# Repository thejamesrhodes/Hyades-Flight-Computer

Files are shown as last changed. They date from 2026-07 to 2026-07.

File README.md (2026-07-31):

<p align="center">
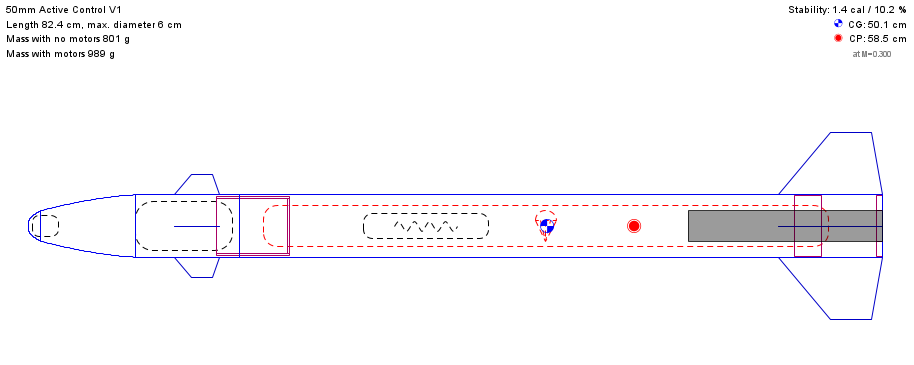
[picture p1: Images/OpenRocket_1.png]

</p>

---

# Hyades Flight Computer

Custom STM32H743 flight computer and GNC software for an actively roll-controlled high-power rocket.






*This is an engineering project, not a product. The safety case, regulatory compliance, and airworthiness of any vehicle built from this material are the builder's sole responsibility.*

The project is designed to:
- Provide a modular active roll-stabilisation system suitable for a wide range of high-power rockets.
- Improve flight data quality by reducing excessive vehicle roll.
- Improve parachute deployment reliability by limiting roll-induced line twist.
- Provide a reusable avionics platform for future guidance, navigation and control research.
- Maintain compliance with applicable rocketry regulations through both hardware and software design decisions.
- Release all hardware, firmware and simulation tools as open source.

This repository contains the hardware design, embedded software, simulation models, and analysis tools used during development.

---

## Specification

## Specification

| Parameter | Specification |
|---|---|
| Purpose | Active roll stabilisation for mid- and high-power rockets |
| Flight Computer | STM32H743 ARM Cortex-M7 |
| Control Surfaces | Four independently actuated canards |
| Control System | Configurable closed-loop roll controller with dynamic-pressure gain scheduling |
| Interfaces | I²C, UART and 6× PWM outputs |
| Data | On-board logging with optional telemetry |
| Simulation | MATLAB, Simulink, 6DOF modelling and Monte Carlo analysis |
| Architecture | Modular flight computer, sensor board and power distribution board |
| Design Goals | Low mass, modular, reliable and adaptable |
| License | Apache 2.0 |

---

## Project Progress

| Feature | Status |
|---|:---:|
| Flight Computer Design | ✅ Complete |
| Flight Computer Testing | 🚧 In Progress |
| Flight Software | 🚧 In Progress |
| Flight Hardware Design | 🚧 In Progress |
| Flight Hardware Testing | 🚧 In Progress |
| Simulink Roll Model | ✅ Complete |
| Simulink 6DOF Model | ✅ Complete |
| MATLAB Monte Carlo Analysis | ✅ Complete |
| MATLAB Gain Optimisation | ✅ Complete |
| System Integration | ⏳ Not Started |
| HITL Testing | ⏳ Not Started |
| Flight Testing | ⏳ Not Started |

---

## Repository Structure

```text
Hyades-Flight-Computer
│
├── Firmware/
├── Hardware/
│   ├── PDB/
│   └── MCU Board/
├── Simulation/
│   ├── Buck Regulator/
│   ├── HSE Clock/
│   └── Roll Tuning/
├── Images/
└── Documentation/
```

---

## Flight Computer Design

The main PCB, containing all the computation and data gathering.

<p align="center">
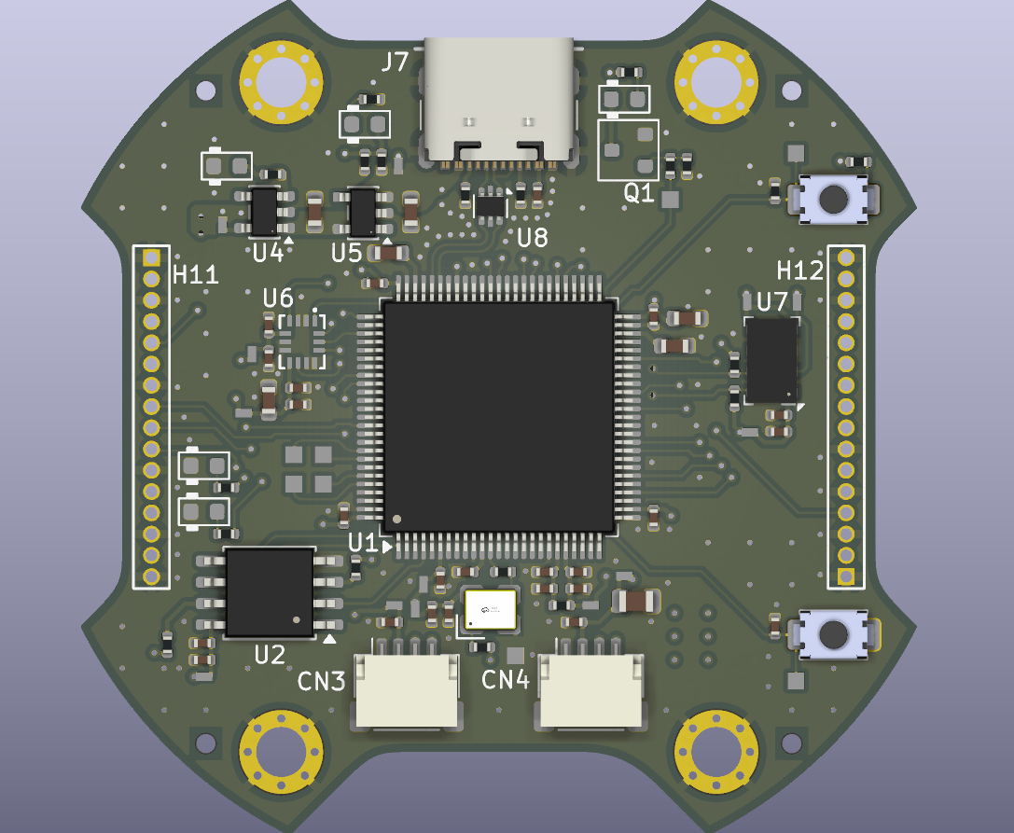
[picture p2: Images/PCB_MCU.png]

</p>

The PDB board, provides power and distributes PWM signals to the servos, as well as providing a clean 3V3 to the sensor board.

<p align="center">
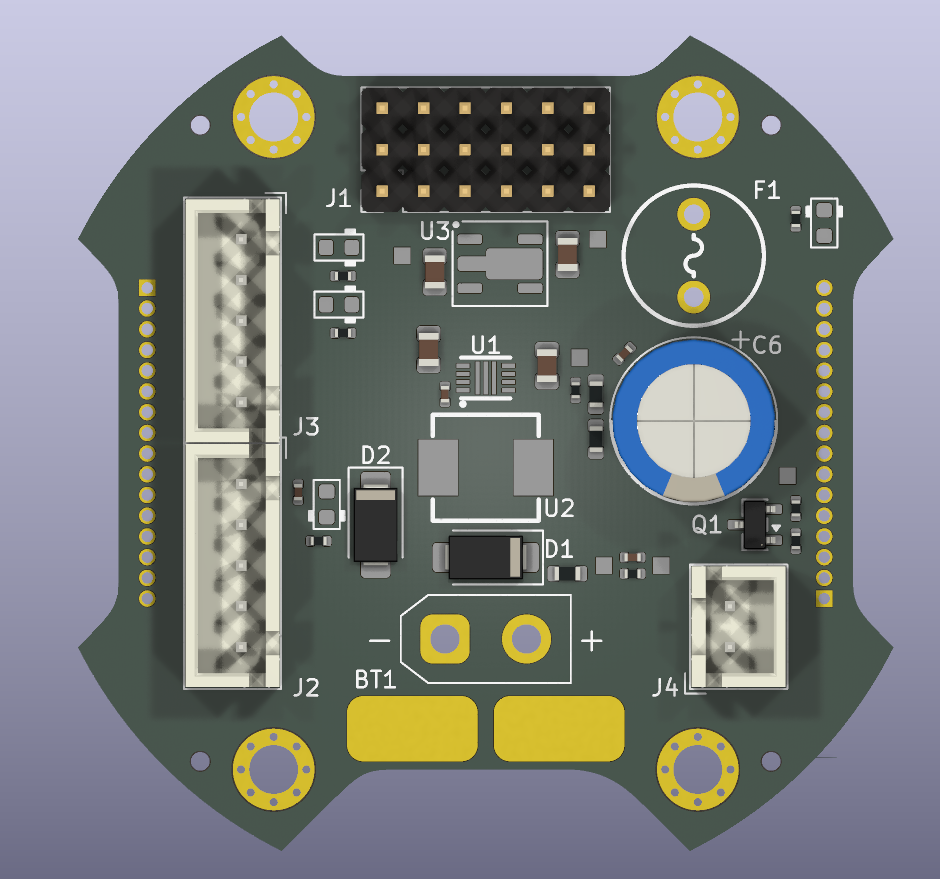
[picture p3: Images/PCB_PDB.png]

</p>

---

## Flight Computer Testing

0 Ohm Series Termination vs 47 Ohm Series Termination for the 24Mhz HSE Oscillator, unnecessary? Yes, but a good opportunity to learn SPICE Simulations, plus it looks cool.
Below the schematic that the simulations where derived from.

<p align="center">
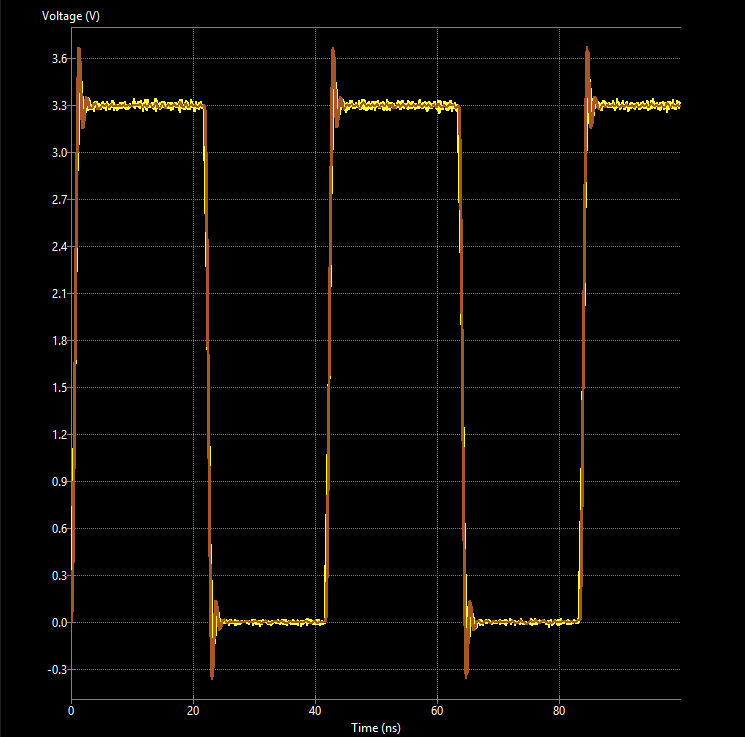
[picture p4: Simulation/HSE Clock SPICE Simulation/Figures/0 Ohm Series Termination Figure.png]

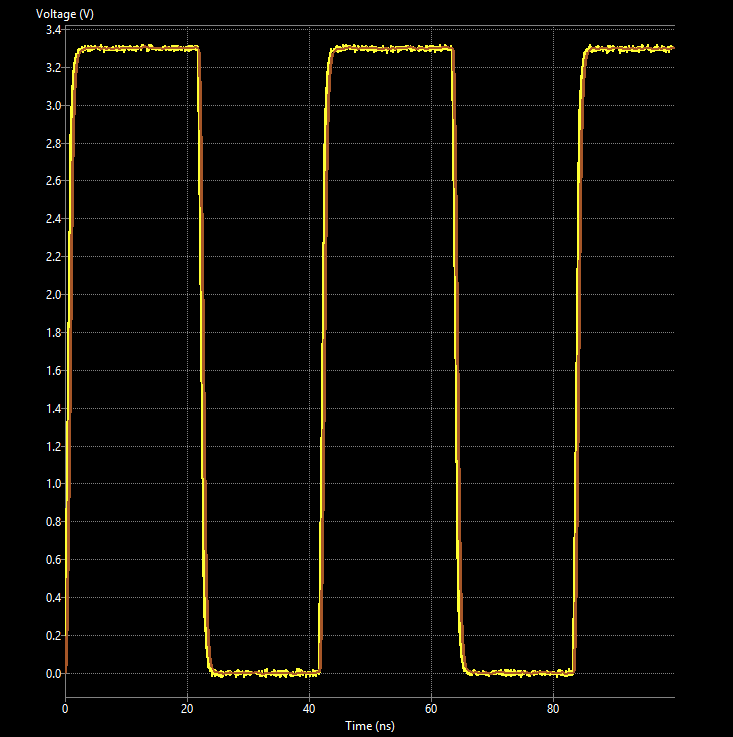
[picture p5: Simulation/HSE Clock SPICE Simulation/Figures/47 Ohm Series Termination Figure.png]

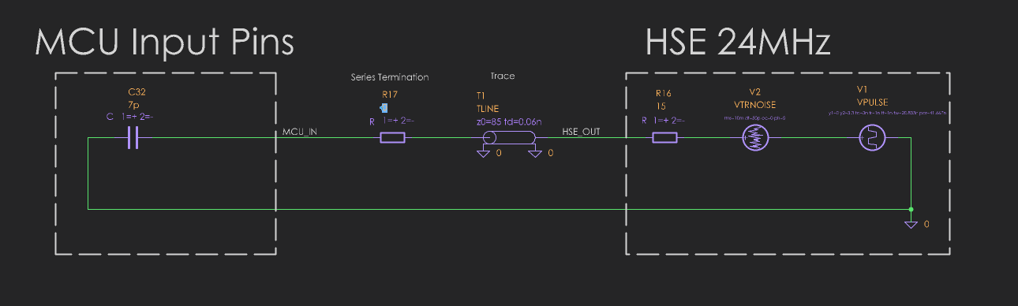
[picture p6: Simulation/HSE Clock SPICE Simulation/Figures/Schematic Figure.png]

</p>

---

## Flight Hardware Design

Full assembly, front section and nose cone are missing in action.

<p align="center">
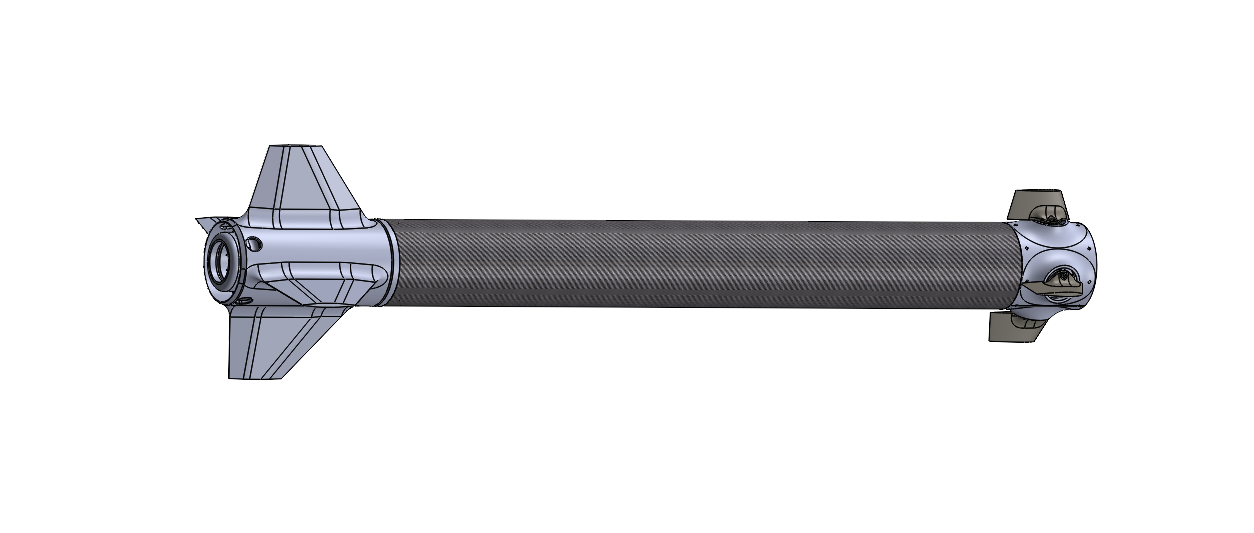
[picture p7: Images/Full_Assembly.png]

</p>

Spinning Rear Fin Can designed to avoid the roll reversal phenomenon where upstream control surfaces tip vortices interact with the downstream fixed fins, causing a difficult to predict moment in the opposite direction.
Front avionics assembly, WIP
<p align="center">
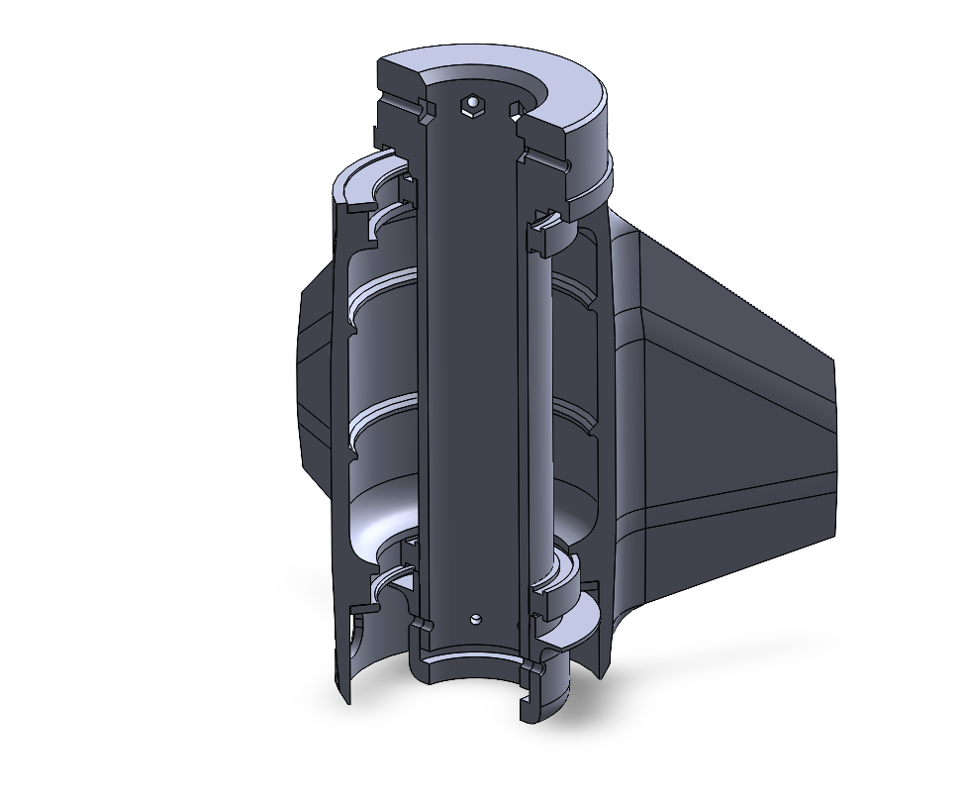
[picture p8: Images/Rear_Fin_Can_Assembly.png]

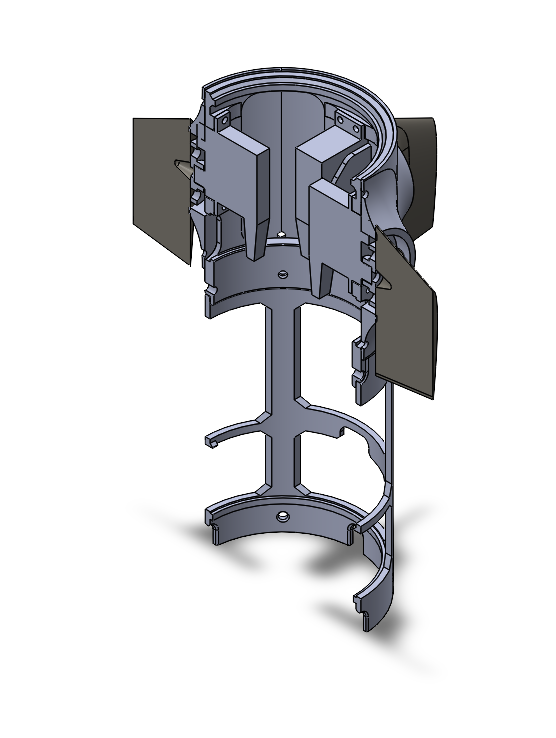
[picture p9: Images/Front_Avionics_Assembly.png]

</p>

---

## Flight Hardware Testing

%words

---

## Flight Software

%words

---

# Simulation

---

## Simulink Roll Model

%words

---

## Simulink 6DOF Model

%words

---

## MATLAB Monte Carlo Analysis

Montecarlo (n = 4000) Demonstrating a <0.5s roll rate settling time for a step response with the current optimal gainset.

<p align="center">
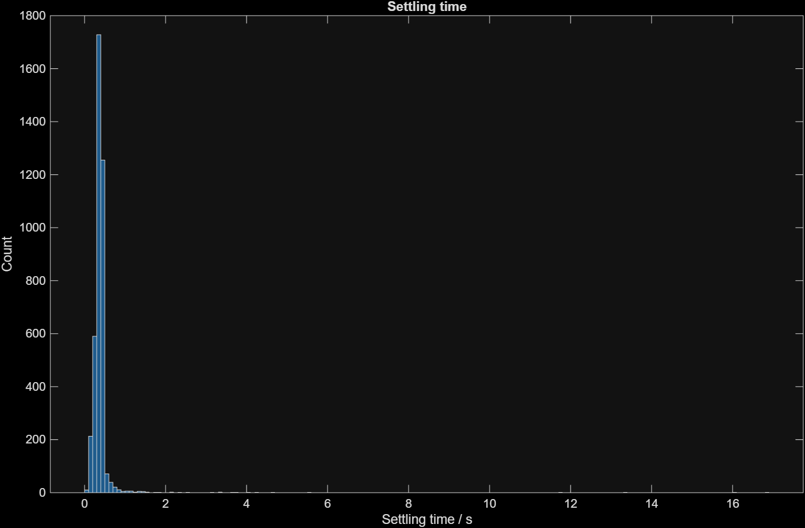
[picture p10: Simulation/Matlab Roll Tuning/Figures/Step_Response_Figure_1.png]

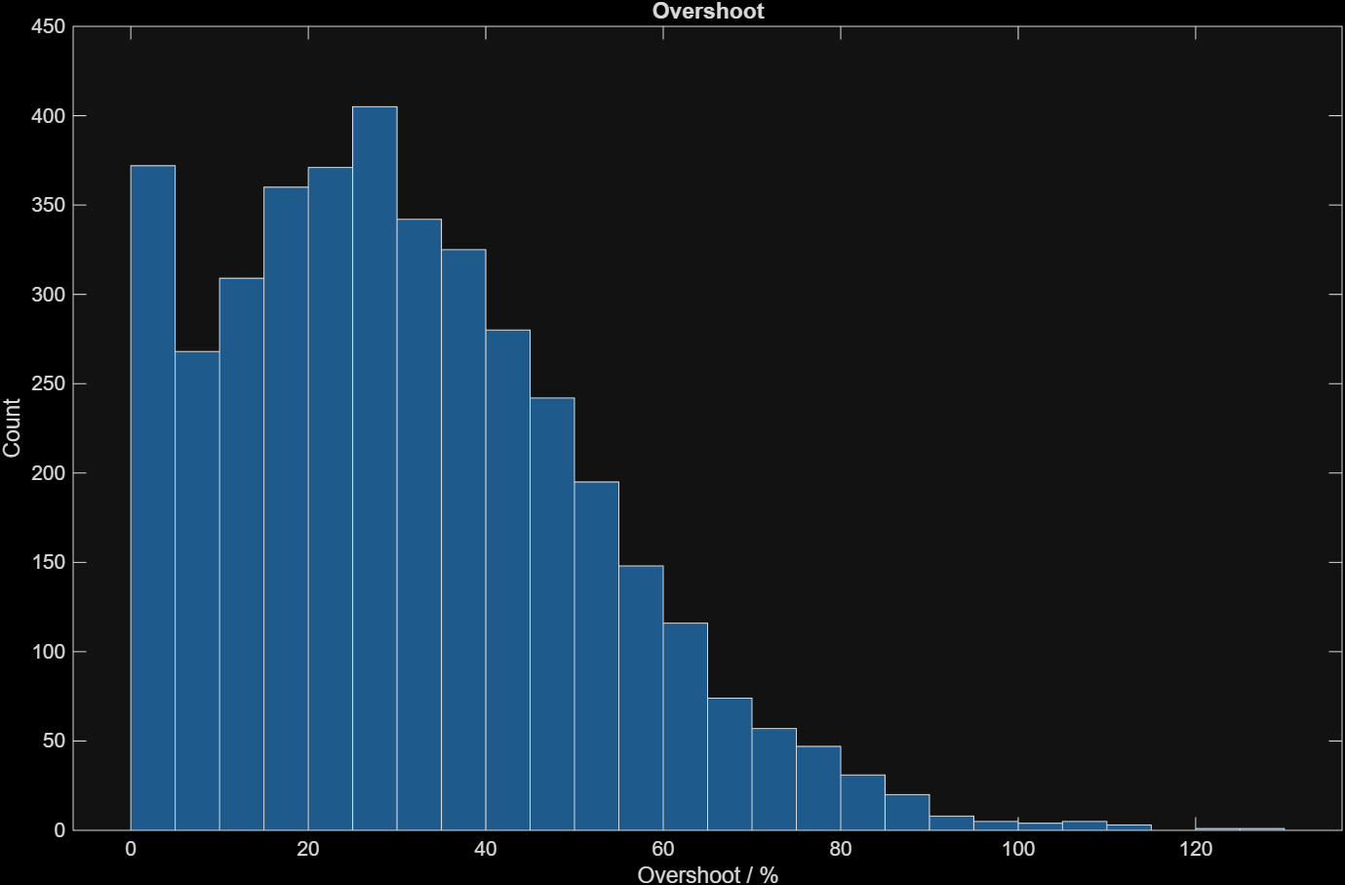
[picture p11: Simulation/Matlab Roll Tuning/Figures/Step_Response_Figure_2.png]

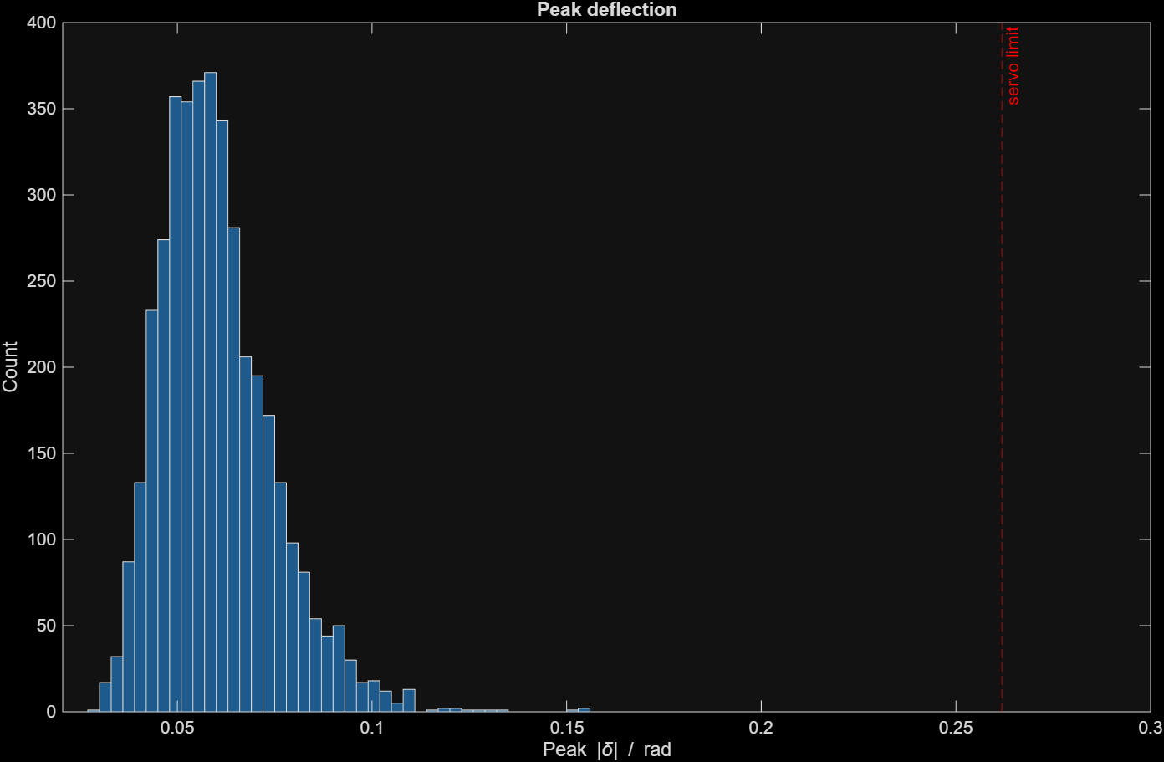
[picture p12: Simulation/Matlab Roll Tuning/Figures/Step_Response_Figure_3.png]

</p>

Visualises the correlation structures between convergent roll damping and the different parameters.

<p align="center">
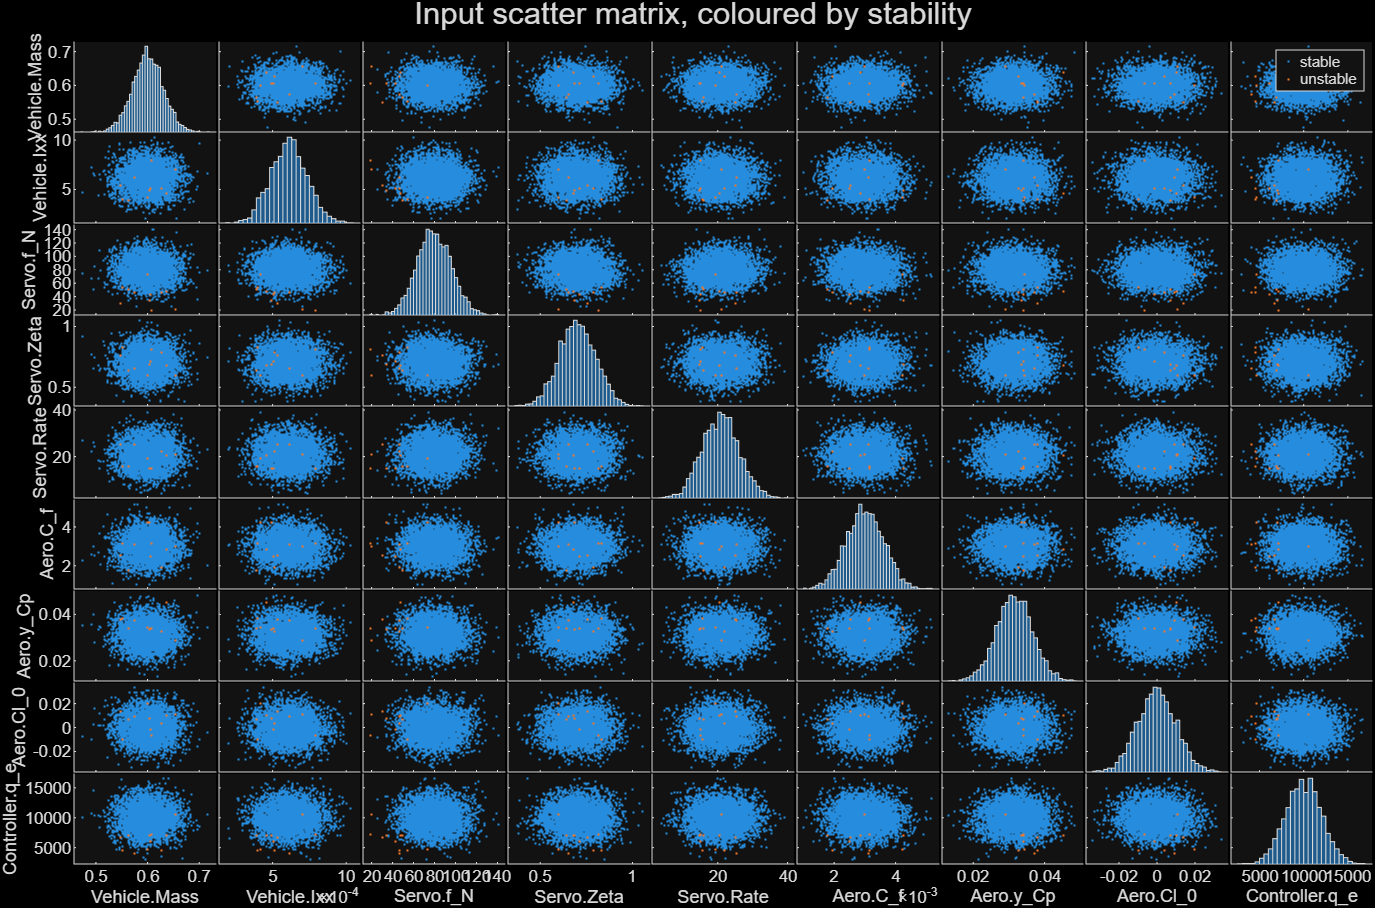
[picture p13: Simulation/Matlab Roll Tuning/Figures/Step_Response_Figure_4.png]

</p>

---

## MATLAB Gain Optimisation

Controller gains are parameterised using dynamic-pressure-normalised coefficients to maintain approximately constant closed-loop behaviour throughout ascent. A grid search evaluates each gain combination using 400 Monte Carlo simulations and scores them according to settling time, overshoot, actuator demand and stability margin. (note gains are q normalised as follows: Kp = c/q  and  Ki = Kp*Ti, where q is dynamic pressure (Pa), c and Ti are the user configurable parameters.).

<p align="center">
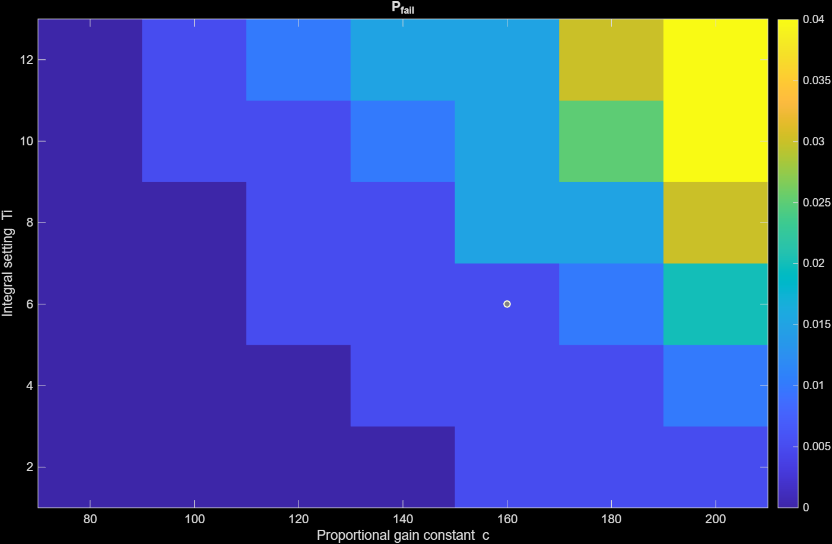
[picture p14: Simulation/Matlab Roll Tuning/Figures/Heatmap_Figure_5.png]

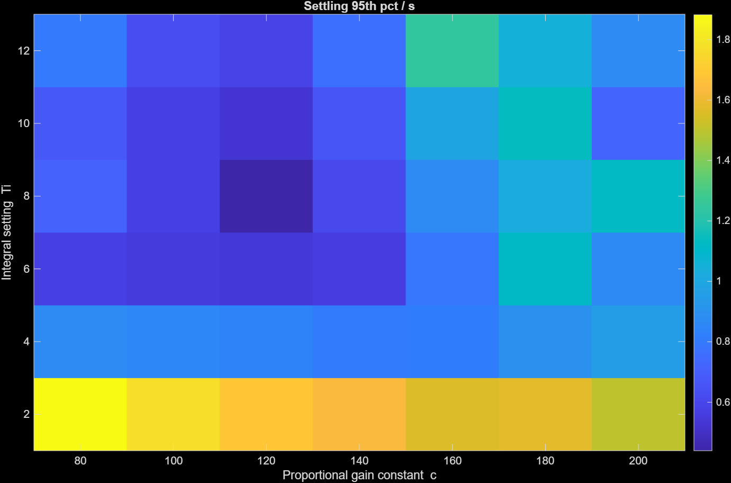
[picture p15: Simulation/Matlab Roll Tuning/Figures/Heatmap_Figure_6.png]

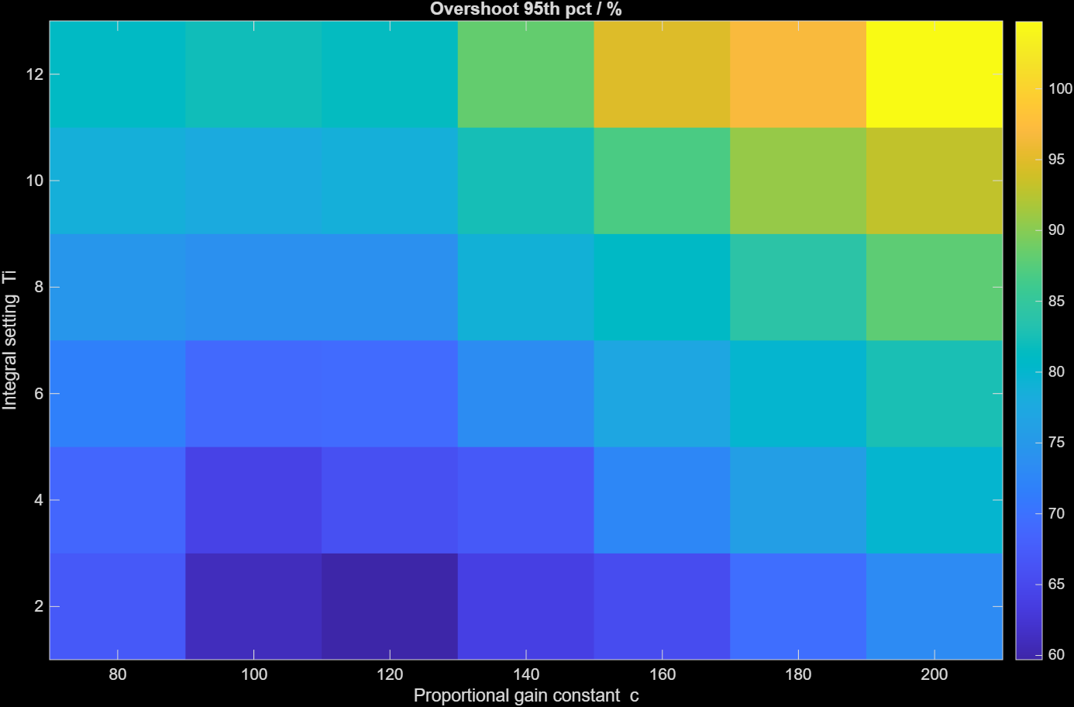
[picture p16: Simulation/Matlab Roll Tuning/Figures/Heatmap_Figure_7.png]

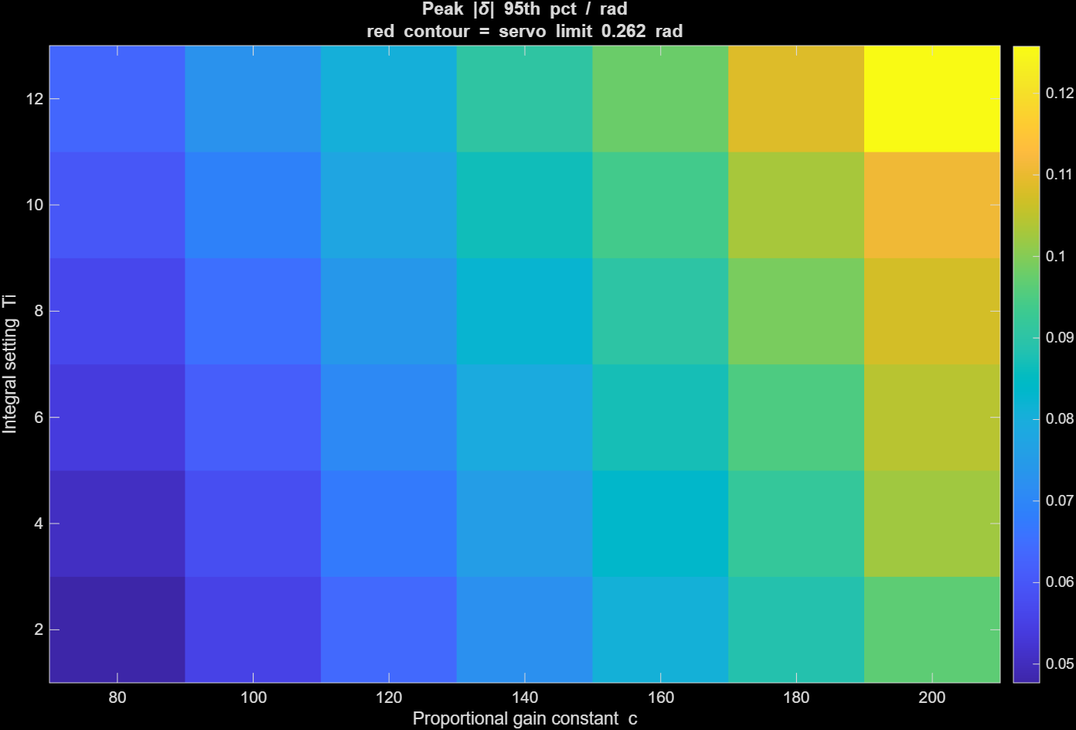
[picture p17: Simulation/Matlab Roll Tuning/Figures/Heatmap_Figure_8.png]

</p>

---

## System Integration

%words

---

## HITL Testing

%words

---

## Flight Testing

%words

---

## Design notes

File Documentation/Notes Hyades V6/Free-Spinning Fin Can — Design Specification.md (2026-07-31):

**Doc:** HYA-FC-001 · **Rev:** A · **Date:** 2026-07-05 · **Status:** For CAD modelling **System:** Hyades — roll-decoupled rear fin can, 29 mm motor, reusable (printed parts expendable)

---

## 1. Scope and design intent

A rear fin can rotates freely about the roll axis on two ball bearings, decoupling rear-fin roll torque from the airframe (prevents roll reversal against the forward canards). The bearings ride on an aluminium journal tube that is **also** the motor mount and thrust column: motor thrust passes journal → printed inner mount → M3 bolted friction joint → CF airframe, **bypassing the bearings and fin can entirely**.

**Design rules (binding):**

- R1 — No thrust-path element may bear on the rotating fin can. Motor retention reacts into the journal/mount only.
- R2 — Fins uncanted (0°). A seized bearing must revert the vehicle to a conventional fixed-fin configuration (verified benign).
- R3 — Printed parts (fin can, inner mount) are consumables; journal cartridge (journal + bearings + spacer + retainers) and fasteners are reused across prints.
- R4 — Mass is minimised wherever it does not erode a stated margin.

**Conventions:** SI units, mm in CAD. Station axis `STA` along the roll axis, **origin at the fin root leading-edge plane, positive aft**. "Radial" ⟂ roll axis. All loads below are **ultimate** (α = 10° gust at V = 300 m/s) unless noted.

---

## 2. Master parameter table (SolidWorks global variables)

Copy into Equations → Global Variables. Names are CAD-safe. `[A]` = assumption, revisit; `[F]` = fixed by prior analysis/fact; `[D]` = derived, update if a parent changes.

|Variable|Value|Unit|Basis|
|---|---|---|---|
|`D_AIRFRAME_OD`|61.0|mm|[F] airframe|
|`D_AIRFRAME_ID`|59.0|mm|[F] 1 mm CF wall|
|`D_MOTOR`|29.0|mm|[F] motor calibre|
|`D_JOURNAL_ID`|29.3|mm|[D] motor +0.3 clearance|
|`D_JOURNAL_OD`|35.0|mm|[F] = bearing bore|
|`BRG_BORE`|35.0|mm|[F] 6807|
|`BRG_OD`|47.0|mm|[F] 6807|
|`BRG_W`|7.0|mm|[F] 6807|
|`STA_BRG_FWD`|−5.0|mm|[A] see §5 (straddle CP)|
|`STA_BRG_AFT`|+75.0|mm|[A] see §5|
|`L_BRG_SPACING`|80.0|mm|[D]|
|`STA_FIN_CP`|+39.0|mm|[D] Barrowman, subsonic|
|`C_ROOT`|100.0|mm|[F]|
|`C_TIP`|50.0|mm|[F]|
|`FIN_SPAN`|60.0|mm|[F] exposed semispan|
|`FIN_SWEEP_LE`|43.0|mm|[F]|
|`T_FIN`|4.0|mm|[F] (owner may vary; see §7.3)|
|`R_FILLET`|10.0|mm|[F] curvature-continuous|
|`N_FINS`|4|—|[F]|
|`T_SHELL_BASE`|2.0|mm|[D] §7.1|
|`T_SHELL_PAD`|3.0|mm|[D] §7.1 (or ribs, §7.2)|
|`L_CAN`|130.0|mm|[A] STA −15 to +115|
|`GAP_CAN_AIRFRAME`|0.8|mm|[A] axial running gap, §8|
|`N_BOLTS`|16|—|[F] 8 × 2 planes|
|`D_BOLT`|3.0|mm|[F] M3 × 0.5, class 8.8|
|`T_BOLT_TORQUE`|0.6|N·m|[A] §9, bench-verify|

Load constants (analysis, not geometry): `F_THRUST_ULT = 465 N` (AeroTech I200W cert peak — bounding verified 29 mm I-class); `Q_MAX = 54.0 kPa` (V = 300 m/s SL `[A]`); `CNA_FINS = 9.0 rad⁻¹` (Barrowman incl. body interference); `N_ULT = 248 N` (α = 10°); `A_DRAG = 79 N` (C_D = 0.5 `[A]`).

---

## 3. Assembly architecture and part list

```
AIRFRAME (CF tube, stationary)
 └─ INNER MOUNT (FDM, consumable) ── 16 × M3 friction joint ──> CF tube
     └─ JOURNAL TUBE (Al, reused)  ← thrust column; motor inside
         ├─ BRG_FWD 6807 (locating: inner clamped, outer clamped)
         ├─ INNER SPACER (Al tube, sets L_BRG_SPACING)
         ├─ BRG_AFT 6807 (floating: inner g6 slide + wave washer, outer clamped)
         └─ retainers / clamp ring
     FIN CAN (FDM, consumable, rotating)
         ├─ 2 × bonded Al SEAT SLEEVES (H-tolerance bores the print can't hold)
         ├─ 2 × bolted CAP RINGS (outer-race clamp; removable for reuse)
         └─ 4 × fins (integral)
```

|#|Part|Material / spec|Qty|Reuse class|
|---|---|---|---|---|
|P1|Fin can (shell + fins + seat pockets)|FDM PC or PA-CF (min ASA)|1|consumable|
|P2|Inner mount / thrust bulkhead|FDM PC or PA-CF|1|consumable|
|P3|Journal tube Ø35 × Ø29.3|Al 6061/6082|1|reused|
|P4|Bearing 6807-2RS, 440C stainless|35 × 47 × 7, ISO 15 dims|2|reused|
|P5|Inner spacer tube|Al, Ø35 slip ID|1|reused|
|P6|Seat sleeve, Ø47 K7 bore|Al, machined|2|consumable (bonded)|
|P7|Cap ring (outer-race clamp)|FDM or Al, 3 × M2.5/M3|2|reused|
|P8|Wave washer, Ø35 shaft series|steel|1|reused|
|P9|Bolts M3 × L, class 8.8 + captive nuts + conical spring washers + Ø9 flat washers|ISO 898-1|16 sets|reused|

---

## 4. Interfaces, fits, and tolerances

Fit logic `[inference from standard bearing-fit practice — ring rotating relative to load direction takes the tight fit]`: the radial aero load is fixed in the airframe frame; the **outer rings rotate with the can → circumferential outer-ring load → outer rings must be tight/clamped** (else seat creep). Inner rings see a stationary (point) load → may be loose; **axial float lives at the aft inner ring**. _(Supersedes Rev-0 discussion which floated the outer race.)_

|Interface|Fit / tol|Notes|
|---|---|---|
|Outer race Ø47 in seat sleeve|sleeve bore **K7**, plus mechanical clamp (cap ring); optional retaining compound (Loctite 603-class) as anti-creep|tight side of transition; clamp is the primary retention `[verify against chosen bearing brand's fit table]`|
|Seat sleeve OD in printed pocket|pocket +0.2…+0.4 mm on dia, epoxy-bonded|bond fills FDM tolerance (±0.1–0.3 mm typical)|
|Fwd inner race on journal|Ø35 **js6** zone, clamped shoulder + retainer|locating bearing; takes A_DRAG = 79 N|
|Aft inner race on journal|Ø35 **g6** zone, axial slide + wave washer (P8)|floating; absorbs thermal growth, print tolerance|
|Journal ID / motor|Ø29.3 +0.2/−0|motor retention per R1, into journal only|
|Mount OD / CF tube ID|Ø59 −0.05…−0.15 (slight clearance to light touch)|do **not** design a heavy press fit: FDM CTE ≫ CF hoop CTE, heating grows interference and hoop-stresses the 1 mm wall; keep design interference ≤ 0.1 mm radial|
|Can OD / airframe OD|flush at Ø61, axial gap `GAP_CAN_AIRFRAME`|add labyrinth lip, §8|

Datum scheme (use in every part and the assembly): **A** = journal/roll axis · **B** = fwd bearing seat face (STA reference) · **C** = fin-1 index plane through axis.

---

## 5. Bearing stations and load rationale

Fin CP sits at `STA_FIN_CP` ≈ +39 mm (MAC = 77.8 mm, spanwise CP ȳ = 26.7 mm, subsonic; shifts aft transonic `[inference]`). Bearings are placed to **straddle** the CP:

$$R_\text{fwd} = N_\text{ult}\frac{STA_\text{aft}-STA_\text{CP}}{L_b} = 248\times\frac{36}{80} = 112\ \mathrm{N},\qquad R_\text{aft} = 248\times\frac{44}{80} = 136\ \mathrm{N}$$

vs. 620 N for the cantilevered layout — a 4.5× reduction on the worst bearing. Against 6807-class static rating $C_0 \approx 3\ \mathrm{kN}$ `[verify brand table]`: static safety ≈ 22. Bearing stations are `[A]`-tagged: move them if packaging demands, but keep the CP between them; re-run the two-line formula above if you do.

Axial: drag 79 N → fwd (locating) bearing. Gyroscopic couple negligible (<1 N with 0° cant).

---

## 6. Load and margin summary (carried from analysis, Rev A values)

|Path|Ultimate load|Capacity|Margin|Tag|
|---|---|---|---|---|
|Friction joint (service thrust path)|465 N|≈ 2.0 kN (μ = 0.25, 500 N/bolt retained)|~4×|`[verify μ + relaxation, §9]`|
|Bolt shear (backstop)|58 N/bolt|≈ 2.4 kN (8.8, A_s = 5.03 mm²)|~42×|ISO 898-1|
|CF hole bearing (backstop)|19 MPa|~150 MPa conservative|~8×|`[verify tube coupon]`|
|Bearing radial (aft, straddled)|136 N|C₀ ≈ 3 kN|~22×|`[verify]`|
|Bearing axial|79 N|≫|large|—|
|Fin root bending|12.4 MPa|≥ 60 MPa in-plane (printed PC)|≥ 5×|print orientation §10|
|Fin flutter|300 m/s|V_f ≥ 530 m/s (G = 0.3 GPa)|≥ 1.8×|Martin boundary, rough|
|Shell wall (fin root, local)|see §7|—|≥ 2× at t per §7|—|

---

## 7. Shell wall sizing (mass-minimised)

### 7.1 Governing case and thickness

Global beam bending of the shell between bearings is trivial (σ ≈ 4 MPa at t = 1 mm). The governing case is **local circumferential wall bending where each fin root moment enters the shell**.

Per-fin ultimate root moment $M_f = 3.31\ \mathrm{N,m}$ distributed over the root chord gives a running moment

$$m' = \frac{M_f}{c_r} = \frac{3.31}{0.100} = 33.1\ \mathrm{N,m/m}$$

The wall reacts $m'$ in plate bending. Bounds:

$$\sigma = \frac{6m'}{t^2}\ \text{(all one side, conservative)}\qquad \sigma = \frac{3m'}{t^2}\ \text{(shared both sides, continuous shell)}$$

Design allowable for printed PC/PA-CF in the favourable (in-plane) direction: $\sigma_\text{allow} = 30\ \mathrm{MPa}$ (≈ 50 % knockdown on typical 60+ MPa datasheet flexural strength for FDM voids and warm structure `[assumption — coupon-verify with your filament]`). Then:

$$t_\text{req} = \sqrt{\frac{6m'}{\sigma_\text{allow}}} = 2.6\ \mathrm{mm}\ \text{(one-sided)}\qquad t_\text{req} = 1.8\ \mathrm{mm}\ \text{(shared)}$$

**Specification:**

- `T_SHELL_BASE` = **2.0 mm** everywhere (also the practical FDM printability/handling floor for a Ø61 tube; going below 2.0 saves < 10 g and costs robustness — not worth it).
- Local reinforcement under each fin root to the one-sided bound: either `T_SHELL_PAD` = **3.0 mm** over a strip (axial extent = root chord + fillets + 10 mm ≈ full can length here; circumferential extent = `T_FIN` + 2·`R_FILLET` + 2 × 10 mm ≈ 44 mm arc), **or** the rib option below.

### 7.2 Rib option (preferred for mass)

Instead of pads, run a **pair of internal axial ribs** under each fin root, one each side of the root plane at ≈ ± (`T_FIN`/2 + `R_FILLET`), rib section ≈ 2 mm thick × 5 mm deep, full can length, blended into the bearing-seat bosses. Ribs carry the root couple with bending depth rather than wall thickness — roughly half the added mass of pads for the same stress (≈ +12 g total vs ≈ +25 g for pads `[inference]`). Bonus: ribs tie the fin loads directly into the seat bosses, which is where the load leaves the shell anyway.

### 7.3 Fin thickness note

`T_FIN` = 4 mm is comfortable everywhere (root σ margin ≥ 5×, flutter ≥ 1.8× even at G = 0.3 GPa). If mass-shaving: root bending scales as $1/t^2$ and flutter as $t^{3/2}$; 3 mm keeps root margin ≈ 3× and V_f ≥ ~350 m/s at the weak-print modulus — **legal but thin on flutter margin at V = 300 m/s; keep ≥ 3.5 mm unless the flight sim shows V_max well under 300 m/s.**

---

## 8. Dust, gap, and running clearance

- Axial gap can↔airframe: `GAP_CAN_AIRFRAME` = 0.8 mm nominal (FDM tolerance stack + thermal).
- Add a **labyrinth lip**: 1.5 mm axial overlap ring on the can nesting inside a matching rebate on the airframe side, 0.4 mm radial clearance — shields the forward bearing from dust/exhaust with zero contact. Print-in feature, ~2 g.
- Seals: 2RS contact seals both bearings (reuse + dust). Residual friction ~5–10 mN·m total vs canard roll authority of order 10⁻¹–10⁰ N·m at high q → coupling ≤ a few % where roll reversal matters `[inference]`. If freer spin is wanted near apogee, fit non-contact (RZ) on the protected inboard faces only.

---

## 9. Bolted friction joint (thrust path) — assembly spec

- 16 × M3 × (grip + nut) class 8.8, **through-bolt into captive nuts** (printed hex pockets in mount or bonded tapped ring). No threads in plastic on the thrust path.
- Stack per bolt, outside→in: bolt head / **conical (Belleville) spring washer** / Ø9 flat washer / CF tube / mount / captive nut.
- Torque `T_BOLT_TORQUE` = 0.6 N·m `[A]` → preload ≈ 1000 N fresh, ≈ 500 N assumed retained after viscoelastic relaxation. **Bench-verify:** (i) CF/print friction coefficient (design credit currently μ = 0.25 `[unverified]`), (ii) preload retention at 48 h and at 60 °C.
- **Witness marks** across the CF/mount seam at 4 clock positions — slip indicator, inspect post-flight.
- **Re-torque before every flight** until relaxation data exists; then set an interval.
- Bolt planes ≥ 2–3·d (6–9 mm) from the CF tube's cut end (edge distance / shear-out).

---

## 10. Materials and print process

|Item|Spec|
|---|---|
|Filament|PC or PA-CF preferred; ASA/ABS minimum. **PLA and PETG prohibited** on P1/P2 (motor heat; PLA T_g ≈ 55–60 °C)|
|Orientation|**Axis vertical** (layers ⟂ roll axis). Puts fin span-bending stress and shell circumferential bending stress **in-plane**; the weak interlayer axis sees only the ~4 MPa global axial stress|
|Shell/fins|Shell 100 % solid (it _is_ a wall); fins ≥ 4 perimeters, 100 % solid at ≤ 4 mm thickness (infill saves < 15 g and costs balance symmetry)|
|Thermal|Thermal break (phenolic/glass liner or air gap) between motor case and journal; **measure journal/mount temperature on a static fire** before committing filament and grease (grease limit typ. 120–150 °C)|
|Balance|Static-balance the finished can on the journal; correct with small bore-side material removal. Criticality is low (0° cant) but cheap to do|

---

## 11. Mass budget (estimate, PC at 1200 kg/m³ `[inference]`)

|Item|Mass|Notes / levers|
|---|---|---|
|Shell 2.0 mm × Ø61 × 130 + ribs + seat bosses|~90 g|ribs not pads (−13 g)|
|4 × fins, solid, airfoil factor 0.66|~57 g|`T_FIN` 3.5 mm → −7 g (watch flutter)|
|2 × 6807-2RS 440C|~60 g|`[verify catalogue ~30 g ea]`|
|Journal Ø35 × Ø29.3 × ~145|~110 g|**biggest lever:** thin to 1.5 mm wall between bearing lands → ~−35 g `[verify buckling/thrust column trivially OK]`|
|Spacer, retainers, caps, sleeves|~30 g||
|16 × M3 sets|~25 g|12-bolt variant saves 6 g; keep 16 for CF hole-stress spread|
|**Total**|**≈ 370 g**|rotating portion ≈ 150 g|

Rotating polar inertia estimate $I_p \approx 2.6\times10^{-4}\ \mathrm{kg,m^2}$ (shell 6.5×10⁻⁵ + fins 1.9×10⁻⁴) — for the roll-dynamics model.

---

## 12. Verification checklist

1. Coupon: CF tube bearing/shear-out allowable (or accept 8× margin on the conservative 150 MPa).
2. Bench: μ (CF/print) and bolt preload retention (48 h, 60 °C).
3. Static fire: journal and mount temperatures → filament + grease confirmation.
4. Spin test + torque-feel each flight; replace bearings on any roughness (≈ £5 ea).
5. Post-flight: witness marks (slip), bolt torque, seat sleeve bond, fin roots.
6. Flight sim on the chosen I-load: confirm V_max ≤ 300 m/s or rescale §5–§7 loads by (V/300)².

## 13. Open items

- `STA_BRG_*` and `L_CAN` are packaging placeholders — set in CAD, keep CP straddled.
- μ and preload retention unverified (§9) — until then the joint is formally "friction service / bolt-bearing ultimate."
- 6807 C₀ and mass from the chosen brand's catalogue.
- Journal thin-wall option (§11) — confirm before machining.
- Transonic CP shift if the flight sim shows M > 0.8: recheck straddle condition.

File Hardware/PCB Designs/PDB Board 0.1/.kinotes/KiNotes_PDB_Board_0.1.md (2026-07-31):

# **PDB_Board_0.1 - Design Notes**

## **Overview**
<!-- Brief description of the PCB project -->

## **Schematic Notes**
<!-- Key circuit blocks, design rationale -->

## **Layout Considerations**
<!-- Layer stackup, impedance, keep-outs -->

## **Component Notes**
<!-- Click on designators like R1, C5, U3 to highlight on PCB -->

## **Power Distribution**
<!-- Power rails, decoupling strategy -->

## **Signal Integrity**
<!-- Critical nets, routing constraints -->

## **References**
<!-- Datasheets, application notes, calculations -->

---
*KiNotes - PCBtools.xyz*

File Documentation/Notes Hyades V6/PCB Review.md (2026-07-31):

# Flight‑computer PCB review — MCU board + Power Distribution Board (PDB)

KiCad 10.0 projects, format `20260306` (sch) / `20260206` (pcb). Both boards parsed in full.

---

## 0. Method, scope, and confidence

**What I did.** I parsed every schematic and PCB file directly (KiCad 10 stores each net's _name_ on every pad/track/zone; there is no integer net table). I reconstructed the complete pad→net→pin‑function map for every IC from the PCB net assignments cross‑referenced with each symbol's pin table, then checked power, supervision, clock, bus, and protection topology. Load‑bearing device facts were verified against current datasheets (sources cited inline), not from memory.

**What I did _not_ do.** I did not run a geometric DRC. Trace‑to‑trace clearances, controlled‑impedance geometry, thermal‑relief/via‑stitch quality, copper‑pour stitching, and exact current‑carrying capacity of individual polygons were **not** verified — those need the board open in KiCad or a fab DRC. PCB‑layer comments below (§3) are from stackup, track‑width, via‑size, zone, and outline data only.

**Confidence tags:** `[verified]` = confirmed against a datasheet/primary source; `[fact]` = read directly from your files; `[inference]` = engineering judgement from the netlist; `[verify]` = you should confirm against a spec I couldn't fully pin down.

---

## 1. Board inventory `[fact]`

||MCU board|PDB|
|---|---|---|
|Size / outline|50 × 50 mm, rounded‑rect|50 × 50 mm|
|Stackup|4‑layer: F.Cu / In1.Cu=**GND plane** / In2.Cu=**power** (+3V3/+5V split) / B.Cu|same topology|
|Thickness|1.60 mm|1.66 mm|
|Key ICs|U1 STM32H743VIT6, U3 W25Q128JV (SPI flash), U4 ICM‑42688‑P (IMU), U5 MS5611 (baro), U2 USBLC6‑2P6|U1 TPS62135 (buck), U5 AP2112K‑3.3 (LDO), U3 LM358 (sense), U2 IHLP2525 1 µH, D2 SS34, D1 SMAJ15A|
|Connectors|J7 USB‑C, H8/H9 (2× 16‑pin 1.27 mm board‑to‑board), CN1/CN2 JST‑SH|CN1 XT30 (batt), U6/U7 (mate H8/H9), H9 servo header, JP3 rail‑select|

The MCU board carries **no regulation** — it receives **+3V3 and +5V from the PDB** over H8/H9. All logic (MCU, IMU, baro, flash) runs on the PDB's AP2112K 3.3 V LDO.

---

## PART 1 — SCHEMATIC REVIEW

## 1.1 MCU board — STM32H743 core

### Power / supervision — correct `[verified]`

- `VDD` ×5 (11,27,50,75,100) → +3V3; all `VSS` → GND; `VBAT` (6) → +3V3 (fine with no coin cell). `[fact]`
- `VCAP1`/`VCAP2` (48,73) each to a 2.2 µF (C13/C12) — matches the H743 requirement of 2×2.2 µF. `[verified]`
- `NRST` (14): 10 kΩ pull‑up (R12) + 100 nF (C11) + button (SW1). Standard. `[fact]`
- `BOOT0` (94): 5.1 kΩ pull‑down (R13) + button to +3V3 (SW2). Standard. `[fact]`
- Decoupling: ~11× 100 nF + bulk across the VDD pins and VDDA — well provisioned. `[fact]`

### Clock — correct topology `[fact]`

X1 (ASDM1‑24 MHz **active oscillator**) `Output`→PH0 (OSC_IN); **PH1 (OSC_OUT) left floating** — correct for an external‑clock/HSE‑bypass source. Ensure firmware selects **HSE bypass** mode.

- **L4 [verify]:** X1 pin 1 (`Standby`/enable) is left floating. Most Abracon MEMS oscillators have an internal pull‑up so floating = enabled, but confirm on the ASDM1 datasheet; if not, tie it to +3V3.

### Sensors

**IMU ICM‑42688‑P (U4)** — SPI wiring correct: SCLK→PC10, SDI(MOSI)→PB2, SDO(MISO)→PC11, CS→PB12, INT1→PC7, INT2→PC6, VDD/VDDIO→+3V3. `[fact]`

> **H3 — reserved‑pin error `[verified]`.** Datasheet (InvenSense DS‑000347): **pin 10 (RESV) "should NOT be connected to GND or Logic Low"** — tie to VDDIO or leave floating (internal pull‑up default; VDDIO preferred). **Pin 11 (RESV/NC) "is by default an output pin, should be float (no connection)."** On your board **both pin 10 and pin 11 are tied to GND**. Pin 10 to GND fights the internal pull‑up and is explicitly prohibited; pin 11 is a driven output shorted to GND (contention). Pins 2, 3 → GND and pin 7 → GND are all acceptable/required, so those are fine. **Fix:** cut the GND connection to pins 10 and 11; route pin 10 to VDDIO (+3V3) (or leave open), leave pin 11 open.

**Baro MS5611 (U5)** — correct `[verified]`: `PS`→+3V3 (I²C mode), `CSB`→+3V3, `SDA`→SDA1, `SCL`→SCL1, `SDO` floating (fine in I²C), 4.7 kΩ pull‑ups (R8/R9) present.

### Flash W25Q128JV (U3) — correct `[fact]`

Single‑SPI: CS→PC13, DO→MISO, DI→MOSI, CLK→SCK. `IO2` (/WP) and `IO3` (/HOLD) each pulled to +3V3 via 10 kΩ (R4/R5) — correct so the part isn't held/write‑protected in single‑SPI. (IO2/IO3 don't go to the MCU, so no quad mode — fine for logging.)

### USB

- Data path correct `[fact]`: J7 D±(A6/B6, A7/B7) → USBLC6 → PA12/PA11. USB‑C CC1/CC2 each have a 5.1 kΩ Rd to GND (device/UFP). Good.
- **M2 — VBUS↔buck 5 V contention `[fact/inference]`.** The `+5V` net contains **both** the USB‑C VBUS pins (J7 A4/A9/B4/B9) **and** the PDB feed (H8.3/4), with only a TVS (D1) between them. So the USB host's VBUS is hard‑tied to the PDB buck output (§2.2, ≈5.04 V). With battery **and** USB connected, the two 5 V sources are paralleled with no isolation → the buck can back‑feed the host port. On the MCU board `+5V` powers _only_ the USBLC6 VBUS pin and the VBUS divider — nothing else. **Fix:** give the USB side its own VBUS domain (ideal‑diode/load‑switch OR‑ing, or simply don't route PDB +5 V to the MCU board and don't tie USB VBUS to it), or guarantee only one source is ever present.
- **L1 — VBUS sense + LED `[fact/inference]`.** `USB_VBUS`→PA9 comes from an R1/R2 = 100 k/10 k divider: $V=5\text{ V}\cdot\frac{10\text{k}}{110\text{k}}\approx 0.45\text{ V}$ — a poor "VBUS present" level (and identical logic‑low whether or not USB is present, if read as GPIO). LED1 is tied to this 0.45 V node, so it can't turn on and it loads the divider. Minor; workable in firmware. If you want a USB‑power LED, drive it from +5 V through a series resistor to GND.

### **H1 — analog sense inputs on non‑ADC pins `[verified]`**

`ISHUNT_DELTA` → **PB5 (pin 91)** and `VBAT_SENSE` → **PB6 (pin 92)**, arriving from the PDB via H8.6/H8.7.

On the STM32H743, the ADC inputs are on ports A/C and PB0/PB1 only; **PB5 and PB6 have no ADC channel** (confirmed via ST's own community answer referencing DS12110 Table 2, and the ADC channel list PA0/PA1/PC0‑3 direct+fast, PA6/PC4/PB1 fast). PB5/PB6 are timer/GPIO‑capable but cannot be sampled by the internal ADC. **As drawn, battery voltage and current cannot be measured.**

**Fix (easy):** the sense lines are just connector pins — reassign H8.6/H8.7 on the MCU side to two free ADC‑capable pins. You have plenty unused: PA0, PA1, PA2, PA3, PA4, PA6, PC0–PC5. e.g. `VBAT_SENSE`→PA0, `ISHUNT_DELTA`→PA1. (Then also address L2 below.)

---

## 1.2 PDB — power tree

**Path `[fact]`:** XT30 → `+BATT` → **SS34 series Schottky** (reverse‑polarity protection, ~0.55 V drop @3 A) → `VDD` → **TPS62135 buck** → `+5V` → **AP2112K LDO** → `+3V3`. Servo rail (`JP3‑C`) is selectable via JP3 between `+BATT` and `+5V`, with 1000 µF + 100 µF bulk — a nice feature.

### Buck output — correct `[verified]`

$$V_\text{out}=V_\text{FB}\left(1+\frac{R_{15}}{R_{16}}\right)=0.7\text{ V}\left(1+\frac{62\text{k}}{10\text{k}}\right)=5.04\text{ V}$$ where $V_\text{FB}=0.7\text{ V}$ is the TPS62135 feedback reference (TI datasheet / E2E). Input range 3–17 V covers 2–4S. Correct 5 V rail. `[verified]`

- **L3 [verify]:** output cap is C6 10 µF + C3 1 µF ≈ 11 µF. DCS‑Control parts typically want ~22 µF effective; confirm against the datasheet's recommended $C_\text{out}$ for transient/stability margin (VIN cap C18 = 10 µF and SS/TR = 2.2 nF are fine).

### **H2 — current sense is non‑functional (three independent faults) `[fact + verified]`**

Intended: 10 mΩ shunt (R3) + LM358‑A (U3) → `ISHUNT_DELTA`. As drawn:

1. **Shunt not in series with the load `[fact]`.** `R3.1`→`VDD` and the buck `VIN` (U1.1) is on the **same** `VDD` node. `R3.2`→`ISHUNT-` connects _only_ to the op‑amp inverting input (high‑Z) and a test point. So the load current flows BATT→D2→VDD→buck and **bypasses the shunt** — R3 carries only nA and drops ~0 V. It measures nothing regardless of the amplifier.
2. **Common‑mode / abs‑max violation `[verified]`.** LM358‑A inputs sit at `VDD` (battery potential, ~7–16 V) while the op‑amp is powered from +3V3. LM358 common‑mode range is $0$ to $V^+-1.5\text{ V}\approx1.8\text{ V}$; the onsemi LM358 datasheet also states that for $V_S<32$ V the **absolute‑max input equals the supply** (3.3 V here). Battery‑potential inputs are far outside both → invalid output and possible device damage.
3. **Open loop `[fact]`.** `1OUT`→`ISHUNT_DELTA` has no feedback network back to `1IN−`; the stage runs open‑loop (comparator), no defined gain.

**Fix:** put the shunt **in series** between D2's cathode and the buck VIN (split `VDD` into "pre‑shunt" and "post‑shunt" nodes), and use a **dedicated high‑side current‑sense amplifier rated for the battery common‑mode voltage** (INA180/INA181/INA226‑class), not a 3.3 V LM358. Then route its output to a real ADC pin (H1).

### M1 — voltage sense clips at high battery `[verified]`

LM358‑B buffers the battery divider: $V_\text{REF}=V_\text{DD}\frac{R_2}{R_4+R_2}=V_\text{DD}\frac{33\text{k}}{213\text{k}}=0.155,V_\text{DD}$. The buffer's input/output can only reach $V^+-1.5\text{ V}\approx1.8\text{ V}$ on a 3.3 V supply, so it **clips once $0.155,V_\text{DD}>1.8\text{ V}$, i.e. $V_\text{DD}\gtrsim11.6$ V (~12.2 V battery)** — the top of a 3S/4S range is unreadable. Fine for 2S. (And it lands on PB6 → H1.) **Fix:** power the sense op‑amp from a rail‑to‑rail part and/or lower the divider ratio so the full range stays < ~1.6 V, or drop the buffer and feed a scaled divider straight to an ADC pin with VDDA filtering.

### M4 — input TVS vs cell count `[verify]`

D1 = SMAJ15A: 15 V standoff, ~16.7 V breakdown (min). A **4S** LiPo reaches 16.8 V → the TVS conducts near full charge and overheats. Fine for **≤3S**. Confirm your battery; for 4S use ~SMAJ18A/20A (with margin above pack max and below the buck's 17 V VIN limit — note 4S at 16.8 V is already close to the TPS62135 17 V ceiling).

### M3 — LDO thermals `[inference]`

$P_\text{diss}=(V_\text{in}-V_\text{out})I=(5.04-3.3)I\approx1.74,I$. At 0.25 A → 0.43 W, at 0.35 A → 0.61 W in a SOT‑23‑5 ($\theta_{JA}$ ~150–250 °C/W board‑dependent) → ~65–120 °C rise. An H743 at high clock plus peripherals can sit in that current band. **Verify your 3.3 V budget;** if it's >~0.25 A steady, consider a small **buck** to 3.3 V (you already have the 5 V rail) or a larger‑pad LDO. `[verify]`

### Correct on the PDB `[fact]`

Reverse protection (SS34 series), VIN decoupling, soft‑start cap, EN straps, MODE/VSEL straps, JP3 servo‑rail select with bulk, battery‑present LED (LED1 via 470 Ω). All fine.

## PART 2 — PCB / LAYOUT OBSERVATIONS

From stackup/width/via/zone/outline data only (no geometric DRC — see §0).

- **Stackup is appropriate `[fact/inference]`:** In1 solid GND plane, In2 power, outer layers signal + GND pour. Good return paths for the SPI/USB/PWM signals.
- **Track widths `[fact]`:** MCU signals 0.15–0.20 mm (fine at these currents). PDB power uses 1.0 mm (×7) and one 3.0 mm segment; signals 0.25 mm.
    - **[verify] Power/servo current.** By IPC‑2221, ~1.0 mm of 1 oz outer copper ≈ 2 A at 10 °C rise; the single 3.0 mm run (main battery path) more. Check the **sum of worst‑case servo stall currents** on the `JP3‑C` rail and the buck output path against trace width **and via count** (0.6/0.3 mm vias ≈ ~1 A each — parallel enough of them on high‑current nets). This is the one PCB item most worth a hard check.
- **Vias `[fact]`:** MCU mostly 0.5/0.3 mm (0.1 mm annular ring — OK for JLC); PDB 0.6/0.3 mm.
- **[verify] Buck thermal pad:** ensure a full array of GND vias under the TPS62135 QFN pad to the plane (couldn't confirm count from the parse).
- **[verify] Placement:** confirm each MCU VDD 100 nF sits at its pin with a short GND via; keep the USB D± pair matched (USB 2.0 FS is tolerant, so this is minor); keep the X1→PH0 trace short.
- **Mechanical [verify]:** both boards are 50 × 50 mm (~71 mm diagonal). If the airframe internal diameter is ~62 mm (per earlier notes), a 50 mm **square** board won't fit a 62 mm tube (needs ≤ ~43 mm side, or a circular board). Confirm the airframe section these mount in.

---

## Appendix — reference maps (from your files)

**STM32H743 net map (used pins):** PE2 SCK1·PE5 MISO1·PE6 MOSI1·PC13 CS1(flash) | PC10 SCK2·PB2 MOSI2·PC11 MISO2·PB12 CS2·PC7 INT1·PC6 INT2(IMU) | PA8 SCL1·PC9 SDA1(baro) | PA11 USB_D-·PA12 USB_D+·PA9 USB_VBUS | PA13 SWDIO·PA14 SWCLK·PB3 SWO | PA5/PA7/PB0/PB1/PE9/PE11 PWM1‑6 | PB5 ISHUNT_DELTA·PB6 VBAT_SENSE (**H1**) | PD8/PD9 TX1/RX1·PB14/PB15 TX2/RX2·PE7 PPS·PD0‑3 GPIO1‑4.

**H8 (power+PWM to PDB):** 1,2=+3V3 · 3,4=+5V · 5,8,15,16=GND · 6=ISHUNT_DELTA · 7=VBAT_SENSE · 9‑14=PWM1‑6. **H9 (debug+comms):** 1,2,7‑10=GND · 3=PPS · 4=SWCLK · 5=SWDIO · 6=SWO · 11=RX1 · 12=TX1 · 13,14=GPIO1,2 · 15,16=+3V3.

**PDB power tree:** XT30→SS34→VDD→TPS62135→+5V(5.04 V)→AP2112K→+3V3. Feedback R15 62k/R16 10k. Batt divider R4 180k/R2 33k. Shunt R3 10 mΩ (**H2**).

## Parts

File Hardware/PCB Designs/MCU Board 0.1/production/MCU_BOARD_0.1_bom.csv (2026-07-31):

Designator | Footprint | Quantity | Value | LCSC Part #
C1, C11, C14, C15, C16, C17, C18, C2, C20, C21, C23, C24, C3, C7 | C_0402 | 14 | 100nF | C1525
C10, C4, C5 | C_0402 | 3 | 10nF | C15195
C12, C13 | C_0603 | 2 | 2.2uF | C23630
C19 | C_0603 | 1 | 4.7uF | C19666
C22 | C_0402 | 1 | 1uF | C52923
C6 | C_0402 | 1 | 10uF | C15525
C8 | C_0402 | 1 | 2.2uF | C12530
C9 | C_0603 | 1 | 10uF
CN1, CN2 | SM04B-SRSS-TB_LF_SN | 2 | SM04B-SRSS-TB_LF_SN | C160404
D1 | D_SMF | 1 | SMF6V5A
H1, H2, H3, H4 | Hole, 3mm | 4 | ~
H10, H5, H6, H7 | Hole_Tooling_JLCPCB | 4 | ~
H8, H9 | KH-1_27PH180-1X16P-L7_2 | 2 | KH-1_27PH180-1X16P-L7_2 | C2938407
J7 | KH-TYPE-C-16P | 1 | KH-TYPE-C-16P | C709357
LED1, LED4 | KT-0603R | 2 | KT-0603R | C2286
LED2 | 0805G_Green | 1 | 0805G_Green | C2297
LED3 | 17-21SUYC_TR8 | 1 | 17-21SUYC_TR8 | C2296
Q1 | Q_SOT-23 | 1 | MMBT3904 | C7420353
R1 | R_0402 | 1 | 100kΩ | C25741
R12, R17, R18, R2, R4, R5 | R_0402 | 6 | 10kΩ | C25744
R13, R6, R7 | R_0402 | 3 | 5.1kΩ | C25905
R14, R15, R16, R3 | R_0402 | 4 | 330Ω | C25104
R8, R9 | R_0603 | 2 | 4.7kΩ | C23162
SW1, SW2 | TS-1088-AR02016 | 2 | TS-1088-AR02016 | C720477
TP1, TP2, TP3, TP4, TP5, TP6 | TestPoint_Pad_1.5x1.5mm | 6 | TestPoint
U1 | LQFP-100_14x14mm_P0.5mm | 1 | STM32H743VIT6
U2 | SOT-666 | 1 | USBLC6-2P6
U3 | W25Q128JVSIQTR | 1 | W25Q128JVSIQTR | C97521
U4 | ICM-42688-P | 1 | ICM-42688-P | C1850418
U5 | MS561101BA03-50 | 1 | MS561101BA03-50 | C15639
X1 | ASDM1-24_000MHZ-LC-T | 1 | ASDM1-24_000MHZ-LC-T | C1987235

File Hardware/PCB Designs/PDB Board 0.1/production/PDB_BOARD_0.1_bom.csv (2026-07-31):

Designator | Footprint | Quantity | Value | LCSC Part #
C1, C11, C4 | C_0603 | 3 | 100nF | C14663
C10 | C_1206 | 1 | 100uF | C15008
C18 | C_0603 | 1 | 10uF | C96446
C19 | C_0402 | 1 | 2.2nF | C1531
C2, C3 | C_0603 | 2 | 1uF | C15849
C6 | C_1206 | 1 | 10uF | C13585
CN1 | XT30UPB-M | 1 | XT30UPB-M | C428721
D1 | SMAJ15A_C908769 | 1 | SMAJ15A_C908769 | C908769
D2 | D_SMA | 1 | SS34 | C8678
H1, H2, H3, H4 | Hole, 3mm | 4 | ~
H5, H6, H7, H8 | Hole_Tooling_JLCPCB | 4 | ~
H9 | HX_PZ2_54-3X6P_ZZ | 1 | HX_PZ2_54-3X6P_ZZ | C32713293
J7 | JST_XH_B5B-XH-A_1x05_P2.50mm_Vertical | 1 | Conn_01x05
J8 | PinHeader_1x05_P2.54mm_Vertical | 1 | Conn_01x05
LED1 | KT-0603R | 1 | KT-0603R | C2286
LED2, LED4 | 17-21SUYC_TR8 | 2 | 17-21SUYC_TR8 | C2296
LED3 | 0805G_Green | 1 | 0805G_Green | C2297
R1 | R_0603 | 1 | 100kΩ | C25803
R15 | R_0603 | 1 | 62kΩ | C23221
R16 | R_0603 | 1 | 10kΩ | C25804
R2 | R_0603 | 1 | 33kΩ | C4216
R3 | 1206 | 1 | 10m_1206_250mW
R4 | R_0603 | 1 | 180kΩ | C22827
R5 | R_0603 | 1 | 470Ω | C23179
R6, R7, R8 | R_0402 | 3 | 220Ω | C25091
TP1 | TestPoint_Pad_4.0x4.0mm | 1 | BATT-
TP12, TP13, TP14, TP15, TP16, TP17, TP3, TP4 | TestPoint_Pad_D1.0mm | 8 | TestPoint
TP2 | TestPoint_Pad_4.0x4.0mm | 1 | BATT+
U1 | TPS62135RGXR | 1 | TPS62135RGXR | C167238
U2 | IHLP2525CZER1R0M01 | 1 | IHLP2525CZER1R0M01 | C845018
U3 | LM358DR2G | 1 | LM358DR2G | C7950
U5 | SOT-23-5 | 1 | AP2112K-3.3
U6, U7 | X1311FV-16-C43D24 | 2 | X1311FV-16-C43D24 | C2881448

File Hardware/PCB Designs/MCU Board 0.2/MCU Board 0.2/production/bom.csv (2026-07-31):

Designator | Footprint | Quantity | Value | LCSC Part #
C1, C10, C15, C16, C2, C21, C26, C28, C3, C31, C4, C5, C6, C7, C8, C9 | C_0402 | 16 | 100nF | C1525
C11, C14, C25, C29 | C_0402 | 4 | 10nF | C15195
C12, C13, C24 | C_0603 | 3 | 2.2uF | C23630
C17 | C_0402 | 1 | 4.7uF | C23733
C18, C19, C20 | C_0603 | 3 | 4.7uF | C19666
C22, C23 | C_0402 | 2 | 1uF | C52923
C27 | C_0805 | 1 | 47uF | C16780
C30 | C_0402 | 1 | 10uF | C15525
CN3, CN4 | JST_SH_SM04B-SRSS-TB_1x04-1MP_P1.00mm_Horizontal | 2 | SM04B-SRSS-TB_LF_SN | C160404
H1, H2, H3, H4 | Hole, 3mm | 4 | ~
H10, H5, H6, H7 | Hole_Tooling_JLCPCB | 4 | ~
H11, H12 | KH-1_27PH180-1X16P-L7_2 | 2 | KH-1_27PH180-1X16P-L7_2 | C2938407
J7 | USB_C_Receptacle_GCT_USB4105-xx-A_16P_TopMnt_Horizontal | 1 | KH-TYPE-C-16P
LED1 | 0603 | 1 | LED_0603_Green
LED2, LED4, LED5 | 0603 | 3 | LED_0603_Red
LED3 | 0603 | 1 | LED_0603_Blue
Q1 | SOT-23 | 1 | MMBT3904
R1 | R_0402 | 1 | 47Ω | C25118
R10, R15, R16, R17, R20 | R_0402 | 5 | 330Ω | C25104
R11, R12 | R_0402 | 2 | 5.1kΩ | C25905
R13 | R_0402 | 1 | 33kΩ | C25779
R14 | R_0402 | 1 | 100kΩ | C25741
R18, R19 | R_0402 | 2 | 4.7kΩ | C25900
R2, R5, R6, R7, R8, R9 | R_0402 | 6 | 10kΩ | C25744
R3 | R_0402 | 1 | 1kΩ | C11702
R4 | R_0402 | 1 | 33Ω | C25105
S1, S2 | SW_TS-1088-AR02016 | 2 | Tactile Button, 160gf | C720477
TIE1, TIE10, TIE11, TIE12, TIE13, TIE14, TIE3, TIE4, TIE5, TIE6, TIE7, TIE8, TIE9 | JUMPER_SMD_1x2_tiny_shorted | 13 | NetTie
TP1, TP17, TP18, TP4 | TestPoint_Pad_04 | 4 | TestPoint_Flag
TP11, TP12, TP13, TP14, TP15, TP16, TP2, TP21, TP22, TP23, TP24, TP3, TP5, TP6, TP7, TP8, TP9 | TestPoint_Pad_04 | 17 | TestPoint_Probe
TP19, TP20, TP25 | SolderWirePad_1x01_SMD_2x4mm | 3 | TestPoint_Flag
U1 | LQFP-100_14x14mm_P0.5mm | 1 | STM32H743VIT6
U2 | SOIC-8_5.3x5.3mm_P1.27mm | 1 | W25Q128JVS
U4 | SOT-23-5 | 1 | MAX40200AUK
U5 | SOT-23-5 | 1 | AP2112K-3.3
U6 | ICM-42688-P | 1 | ICM-42688-P | C1850418
U7 | LGA-8_3x5mm_P1.25mm | 1 | MS5611-01BA03-50
U8 | SOT-666 | 1 | USBLC6-2P6
X1 | OSC-SMD_4P-L3.2-W2.5-BL | 1 | ASDM1-24_000MHZ-LC-T | C1987235

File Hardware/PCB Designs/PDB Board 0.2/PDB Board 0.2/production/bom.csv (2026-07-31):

Designator | Footprint | Quantity | Value | LCSC Part #
BT1 | AMASS_XT30UPB-F_1x02_P5.0mm_Vertical | 1 | Battery
C1, C7, C8 | C_0402 | 3 | 100nF | C1525
C19 | C_0402 | 1 | 2.2nF | C1531
C2, C3, C4, C5 | C_0805 | 4 | 10uF | C15850
C6 | CP_Radial_D10.0mm_P5.00mm | 1 | 1000uF_16V
D1 | D_SMA | 1 | SMAJ12CA
D2 | D_SMA | 1 | SS34
F1 | 38216300000 | 1 | 38216300000 | C142713
H1, H2, H3, H4 | Hole_Tooling_JLCPCB | 4 | ~
H10, H9 | KH-1_27PH180-1X16P-L7_2 | 2 | KH-1_27PH180-1X16P-L7_2 | C2938407
H5, H6, H7, H8 | Hole, 3mm | 4 | ~
J1 | ServoPort_06_Vertical | 1 | ServoPort_06
J2, J3 | JST_XH_B5B-XH-A_1x05_P2.50mm_Vertical | 2 | Conn_01x05
J4 | JST_XH_B2B-XH-A_1x02_P2.50mm_Vertical | 1 | Conn_01x02
LED1 | 0603 | 1 | LED_0603_Red
LED2 | 0603 | 1 | LED_0603_Orange
LED3, LED4 | 0603 | 2 | LED_0603_Green
Q1 | SOT-23 | 1 | 2N7002
R1, R11 | R_0402 | 2 | 100kΩ | C25741
R10, R8, R9 | R_0402 | 3 | 220Ω | C25091
R2 | R_0402 | 1 | 100Ω | C25076
R3 | R_0603 | 1 | 9.1kΩ | C23260
R4 | R_0603 | 1 | 56kΩ | C23206
R5 | R_0603 | 1 | 180kΩ | C22827
R6 | R_0402 | 1 | 10kΩ | C25744
R7 | R_0402 | 1 | 470Ω | C25117
TP1, TP2, TP3, TP4, TP7, TP8 | TestPoint_Pad_04 | 6 | TestPoint_Probe
TP10, TP9 | SolderWirePad_1x01_SMD_4x8mm | 2 | TestPoint_Flag
U1 | TPS62135RGXR | 1 | TPS62135RGXR | C167238
U2 | IHLP2525CZER1R0M01 | 1 | IHLP2525CZER1R0M01 | C845018
U4 | Diodes_SOT-89-5 | 1 | AP2115R5A-3.3TRG1

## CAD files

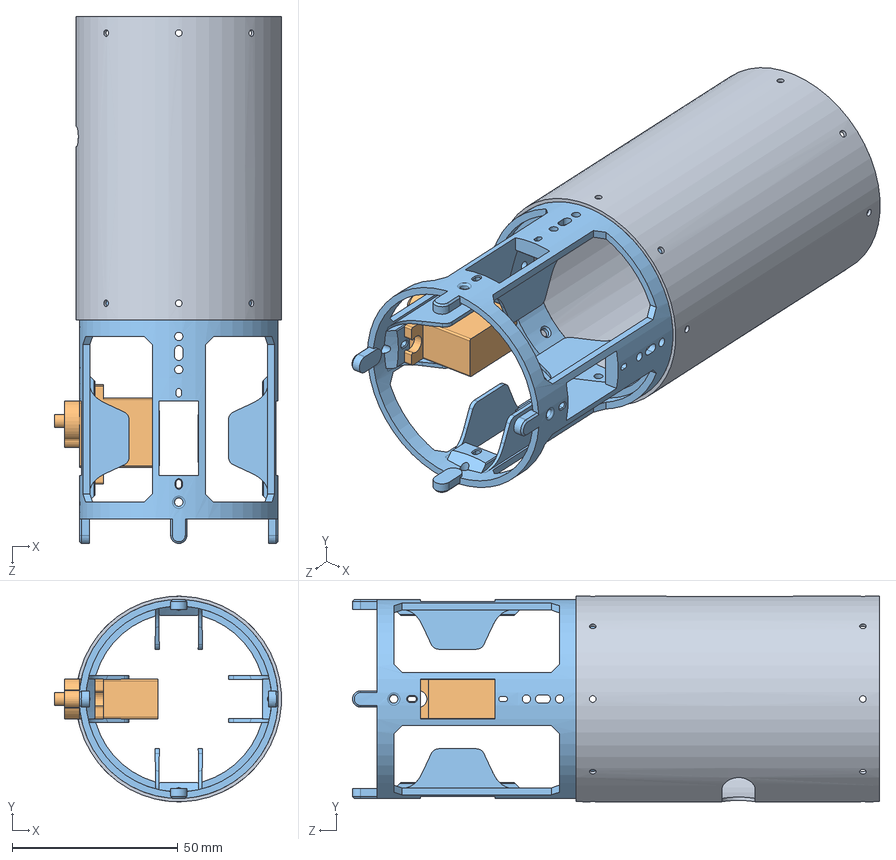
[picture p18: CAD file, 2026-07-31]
Hardware/60mm Rocket/Final Rocket Assembly.SLDASM
68.5 x 62.0 x 159.0 mm
Canard Inner Housing
MG90S Micro Servo
Electronics Bay Outer Housing

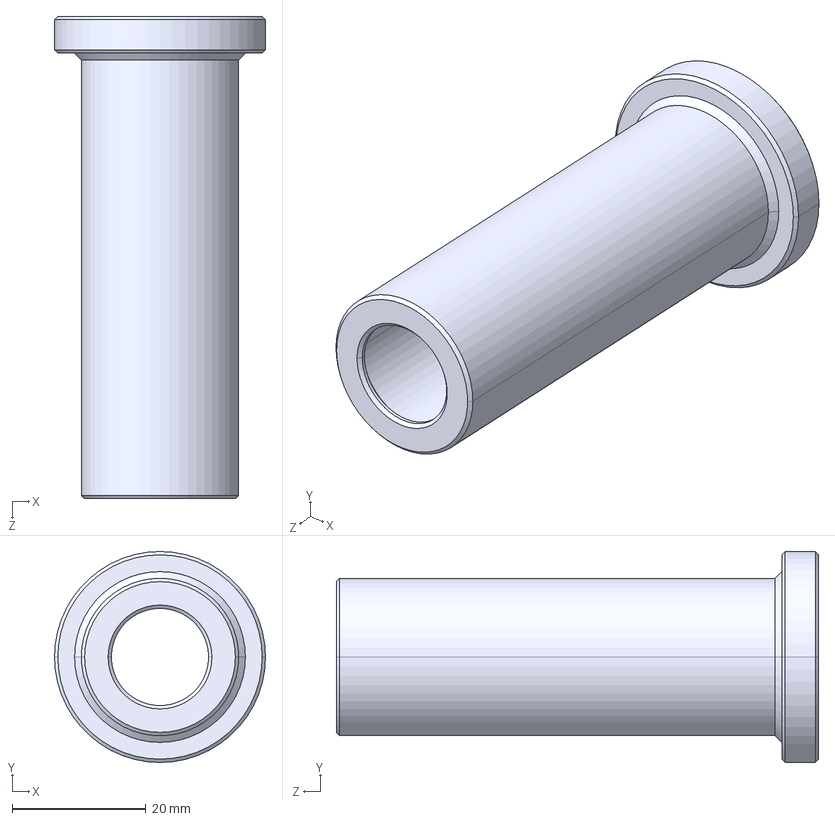
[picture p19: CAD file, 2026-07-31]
Hardware/29mm Rocket/18mm Motor Retainer.STEP
31.5 x 31.5 x 72.0 mm

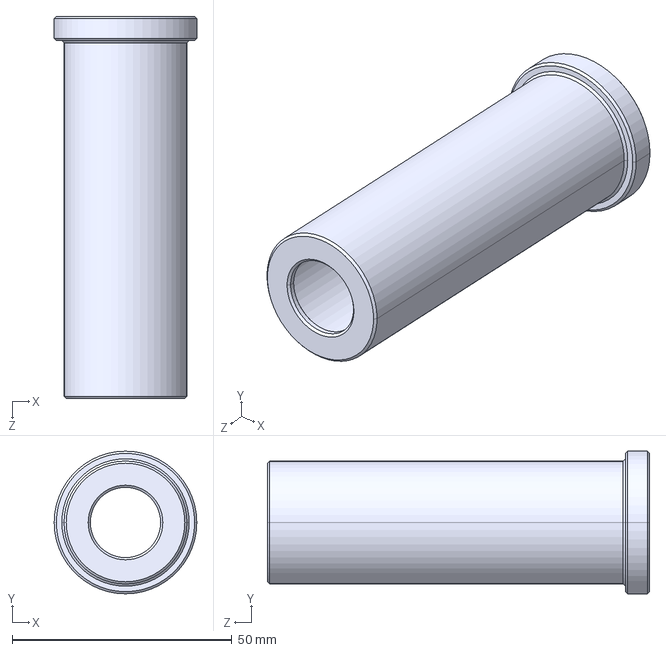
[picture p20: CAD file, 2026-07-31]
Hardware/29mm Rocket/24mm Motor Retainer.STEP
32.5 x 32.5 x 87.0 mm

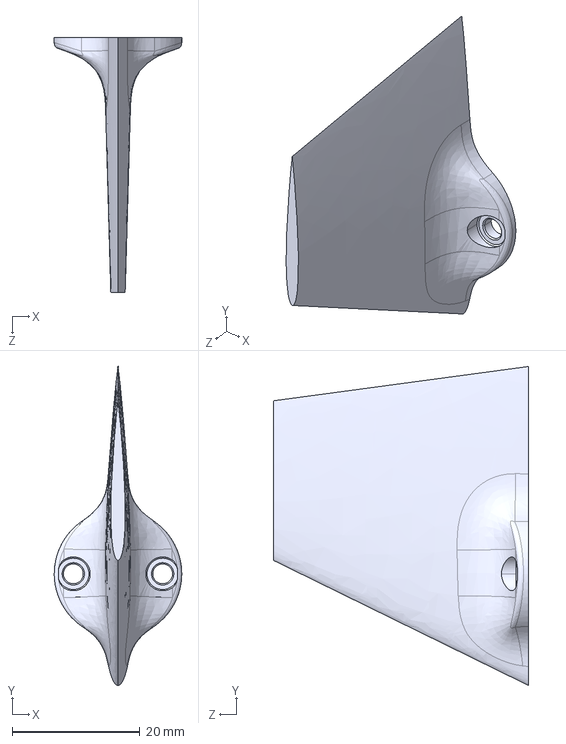
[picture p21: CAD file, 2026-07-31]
Hardware/60mm Rocket/NACA 0009 Canard V2.STEP
20.0 x 50.0 x 40.0 mm

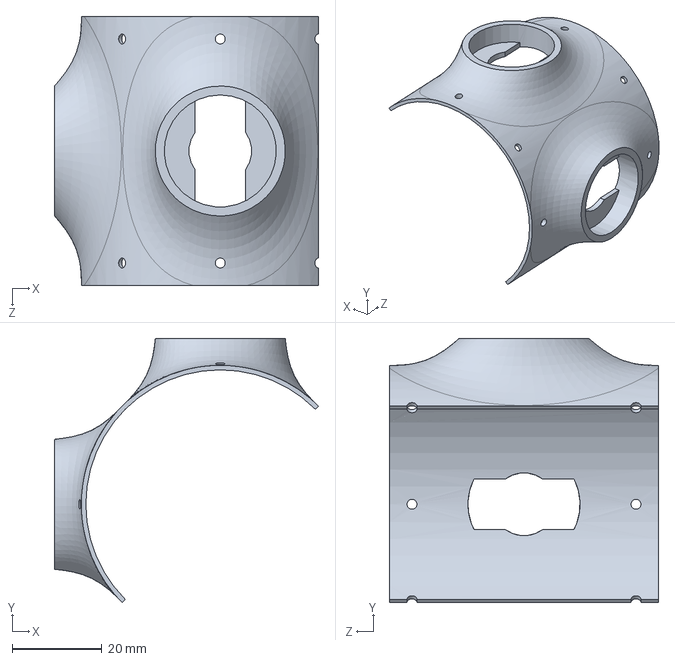
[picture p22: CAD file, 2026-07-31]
Hardware/60mm Rocket/Canard Outer Housing Half.SLDPRT
58.9 x 58.9 x 60.0 mm

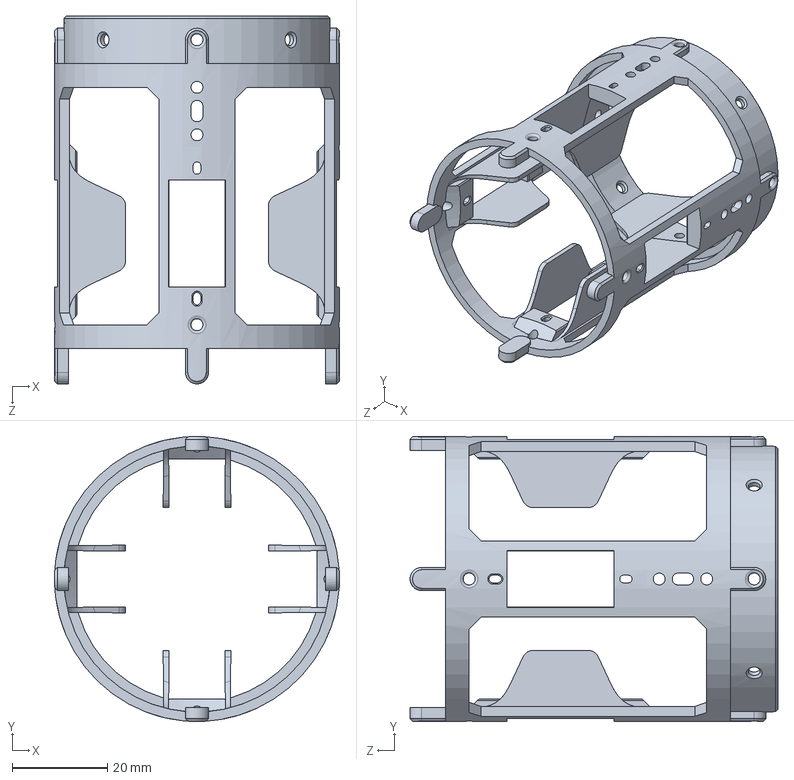
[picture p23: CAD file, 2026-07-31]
Hardware/60mm Rocket/Canard Inner Housing.SLDPRT
60.0 x 60.0 x 77.5 mm

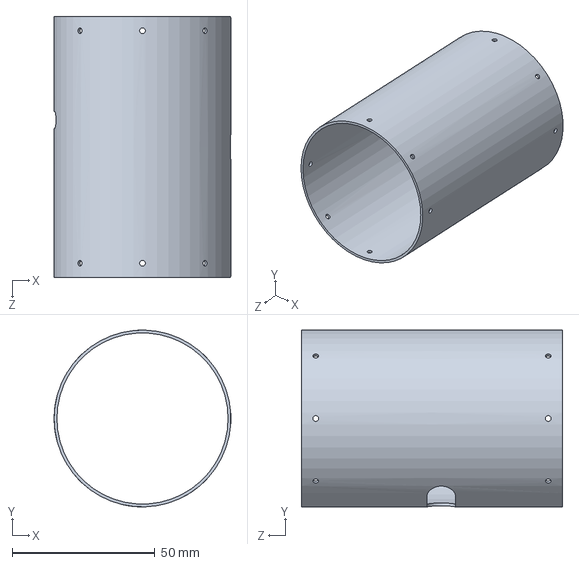
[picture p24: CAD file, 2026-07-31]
Hardware/60mm Rocket/Electronics Bay Outer Housing.SLDPRT
62.0 x 62.0 x 91.5 mm

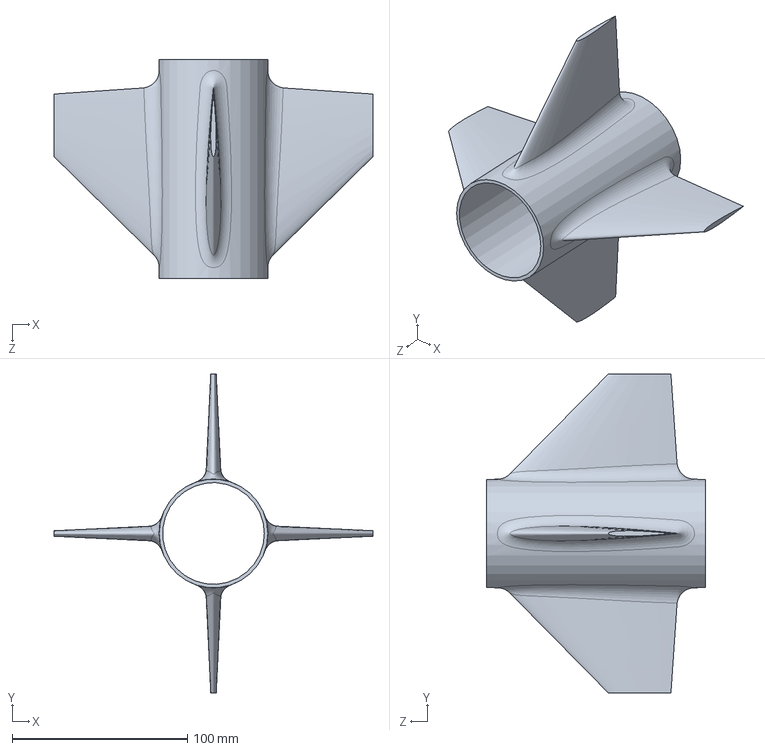
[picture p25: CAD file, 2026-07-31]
Hardware/60mm Rocket/Fin Can.SLDPRT
182.0 x 182.0 x 125.0 mm

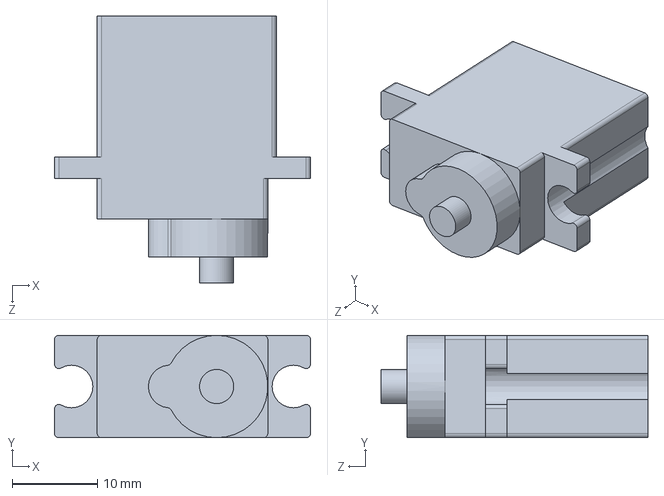
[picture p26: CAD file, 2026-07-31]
Hardware/60mm Rocket/MG90S Micro Servo.SLDPRT
30.0 x 12.0 x 31.2 mm

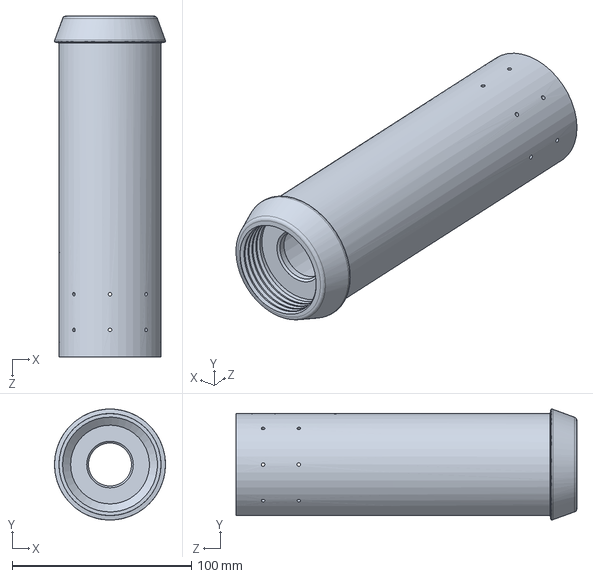
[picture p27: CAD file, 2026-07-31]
Hardware/60mm Rocket/Spinning Fin Can.SLDPRT
62.0 x 62.0 x 190.2 mm

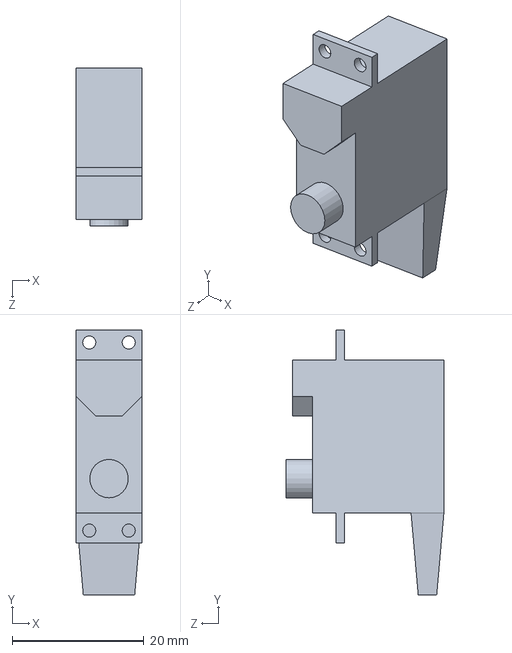
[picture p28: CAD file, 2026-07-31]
Hardware/60mm Rocket/BMS-127WV+.SLDPRT
10.0 x 40.3 x 24.0 mm

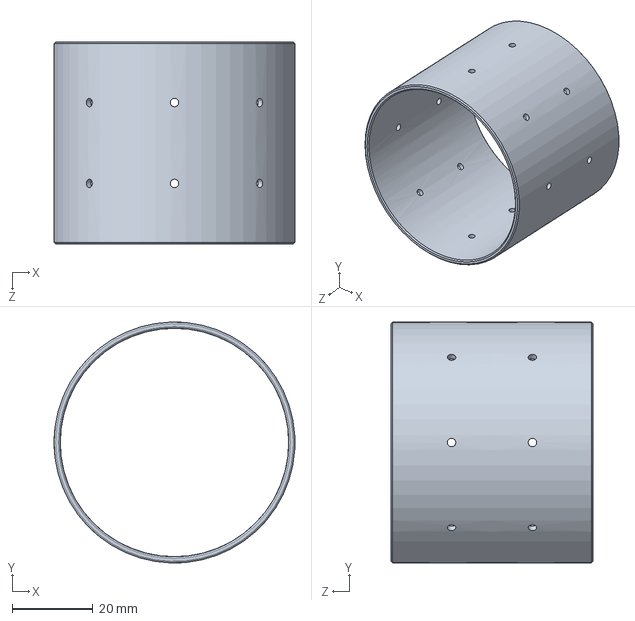
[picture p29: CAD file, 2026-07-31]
Hardware/60mm Rocket/Fin Can Insert.SLDPRT
59.6 x 59.6 x 50.0 mm

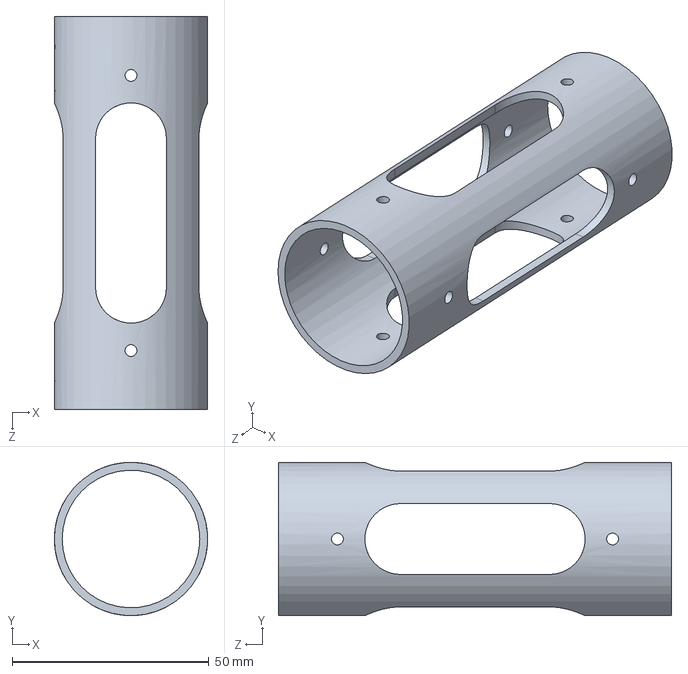
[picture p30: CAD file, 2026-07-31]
Hardware/60mm Rocket/Thrust Mount Bearing Mounting V2.SLDPRT
39.0 x 39.0 x 100.0 mm

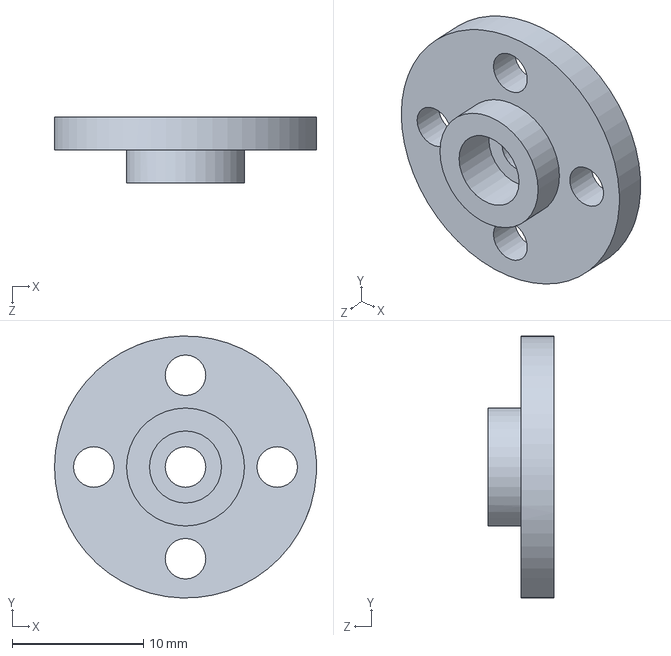
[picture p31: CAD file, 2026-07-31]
Hardware/60mm Rocket/Servo Horn.SLDPRT
20.0 x 20.0 x 5.00 mm

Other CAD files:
Hardware/60mm Rocket/Rear Fins Assembly.SLDASM
Hardware/60mm Rocket/Final Rocket Assembly V2.SLDASM
Hardware/60mm Rocket/Main Assembly V2.SLDASM
Hardware/29mm Rocket/18mm Motor Retainer Simulations.SLDPRT
Hardware/29mm Rocket/18mm Motor Retainer.SLDPRT
Hardware/29mm Rocket/24mm Motor Retainer.SLDPRT
Hardware/60mm Rocket/60mm Alternative.SLDPRT
Hardware/60mm Rocket/6807 Bearing 35x47x7.SLDPRT
Hardware/60mm Rocket/6807 Bearing Clamp.SLDPRT
Hardware/60mm Rocket/6807 Bearing Clamp.STEP
Hardware/60mm Rocket/6807 Bearing Mount.SLDPRT
Hardware/60mm Rocket/Canard Inner Housing V2.3mf
Hardware/60mm Rocket/Canard Inner Housing V2.SLDPRT
Hardware/60mm Rocket/Canard Inner Housing V2.STEP
Hardware/60mm Rocket/Canard Outer Housing.SLDPRT
Hardware/60mm Rocket/Electronics Bay.SLDPRT
Hardware/60mm Rocket/Electronics Sled.SLDPRT
Hardware/60mm Rocket/Fin Can V2.3mf
Hardware/60mm Rocket/Fin Can V2.SLDPRT
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

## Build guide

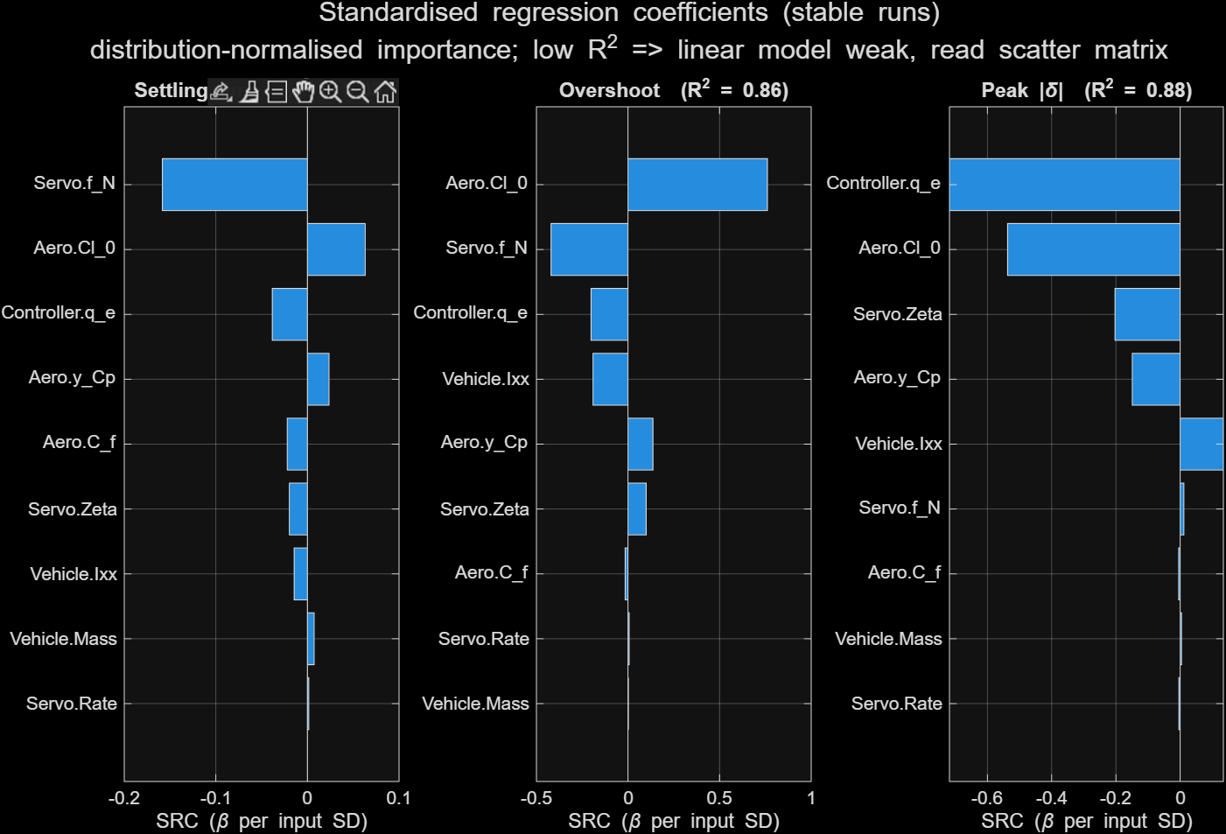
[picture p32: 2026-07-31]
Simulation/Matlab Roll Tuning/Figures/Step_Response_Figure_6.png

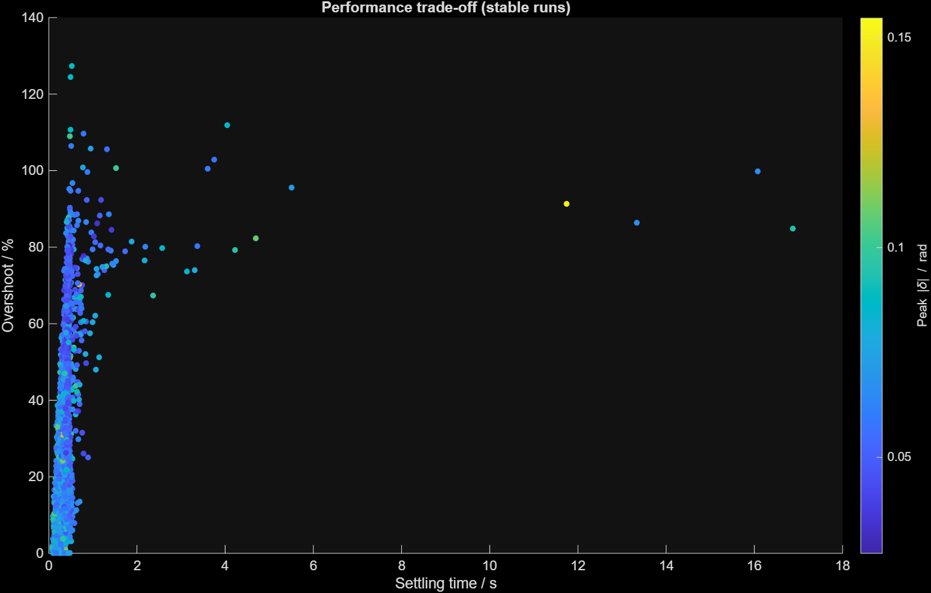
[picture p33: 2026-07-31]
Simulation/Matlab Roll Tuning/Figures/Step_Response_Figure_8.png

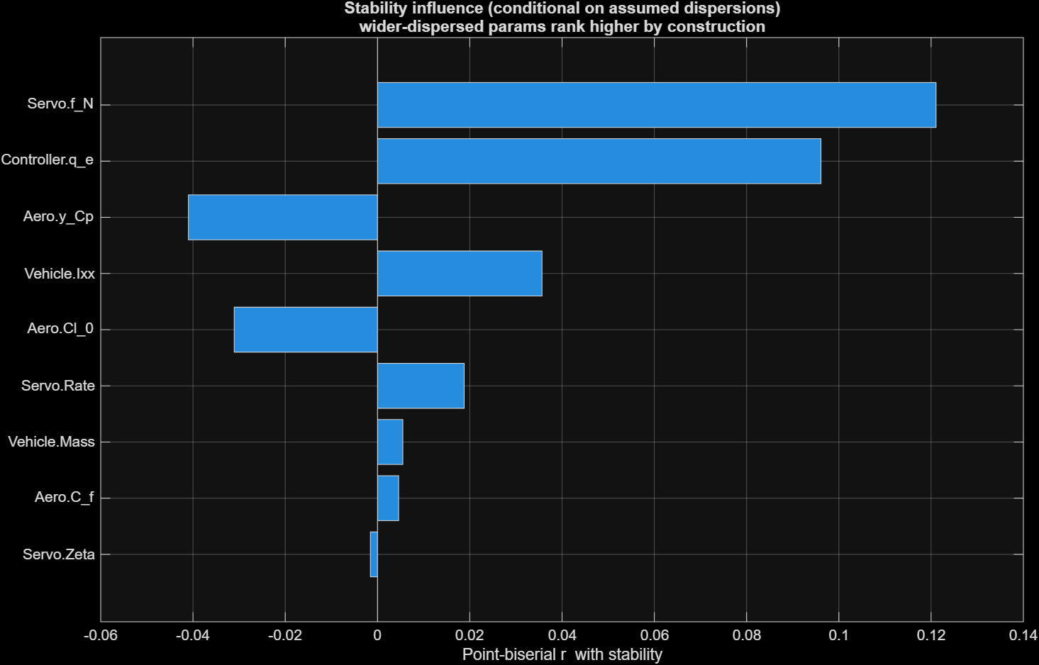
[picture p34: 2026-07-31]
Simulation/Matlab Roll Tuning/Figures/Step_Response_Figure_5.png

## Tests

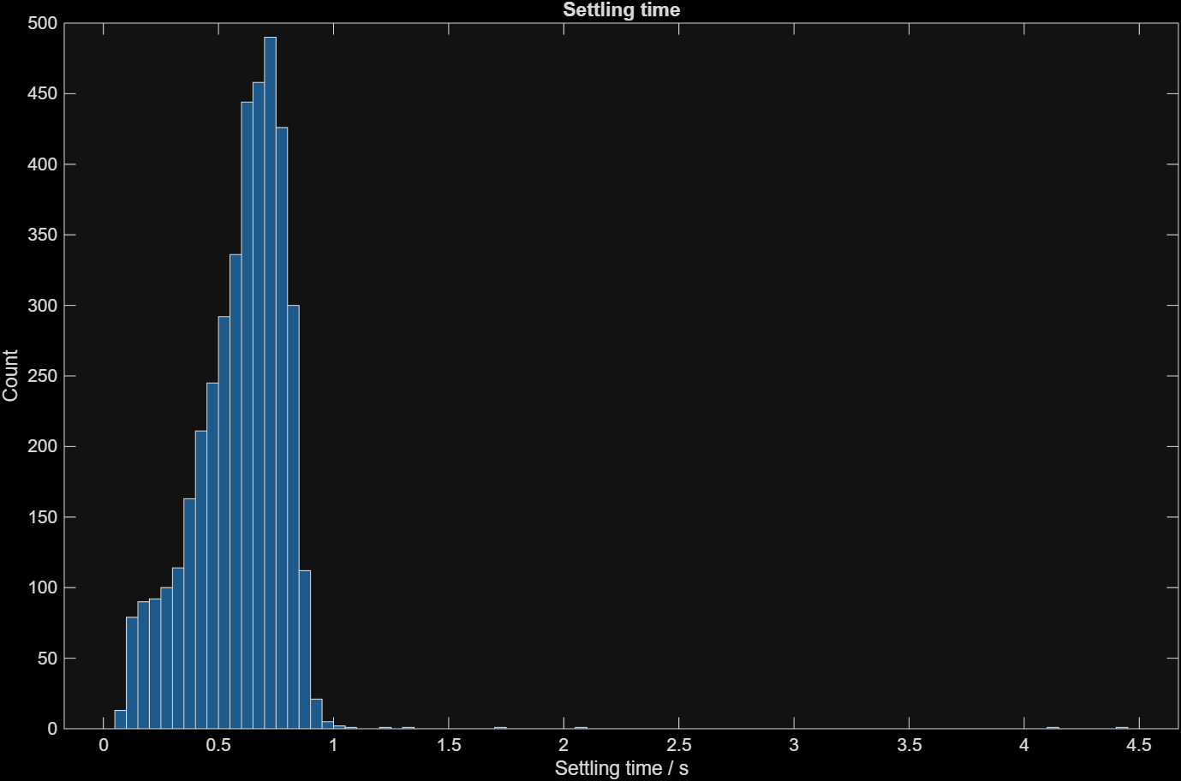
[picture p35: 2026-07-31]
Simulation/Matlab Roll Tuning/Figures/Figure_1.png

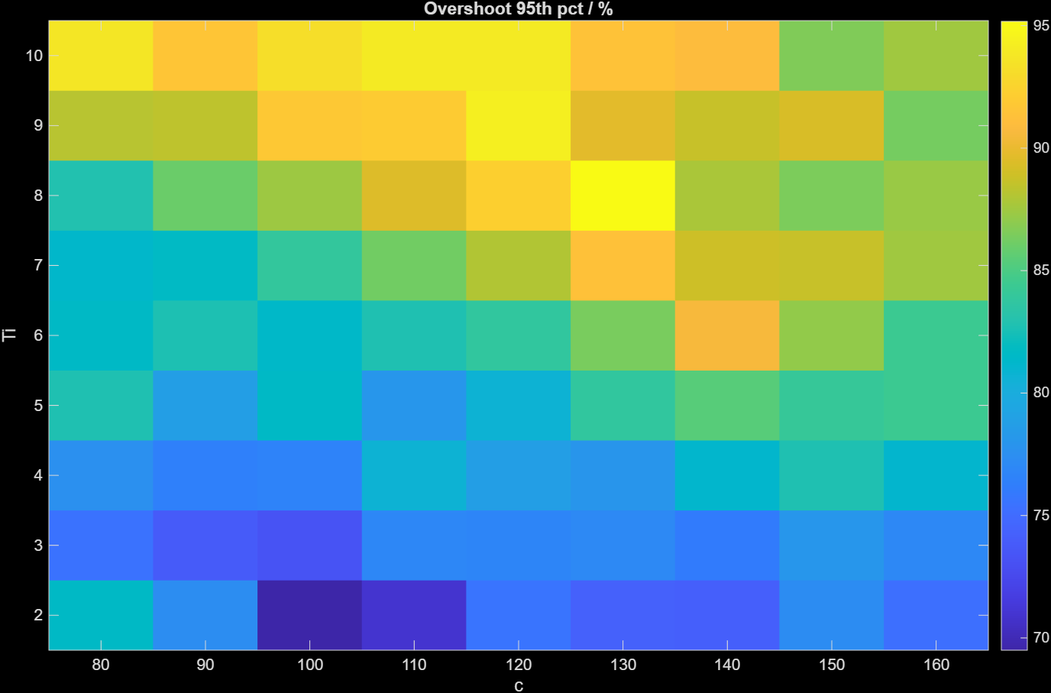
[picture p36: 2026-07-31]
Simulation/Matlab Roll Tuning/Figures/Heatmap_Figure_3.png

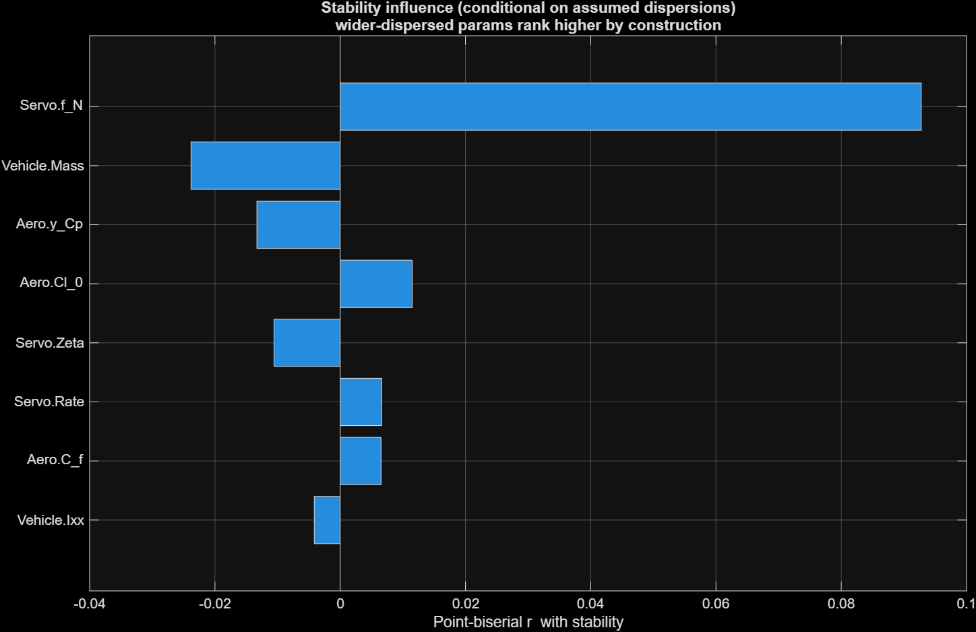
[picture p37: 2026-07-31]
Simulation/Matlab Roll Tuning/Figures/Figure_11.png

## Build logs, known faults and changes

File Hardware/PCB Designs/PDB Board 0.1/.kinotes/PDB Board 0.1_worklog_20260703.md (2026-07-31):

# Work Log — PDB Board 0.1
**Total: 0h 0m**

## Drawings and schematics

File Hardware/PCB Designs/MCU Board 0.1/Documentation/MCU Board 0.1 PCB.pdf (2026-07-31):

R 27.068

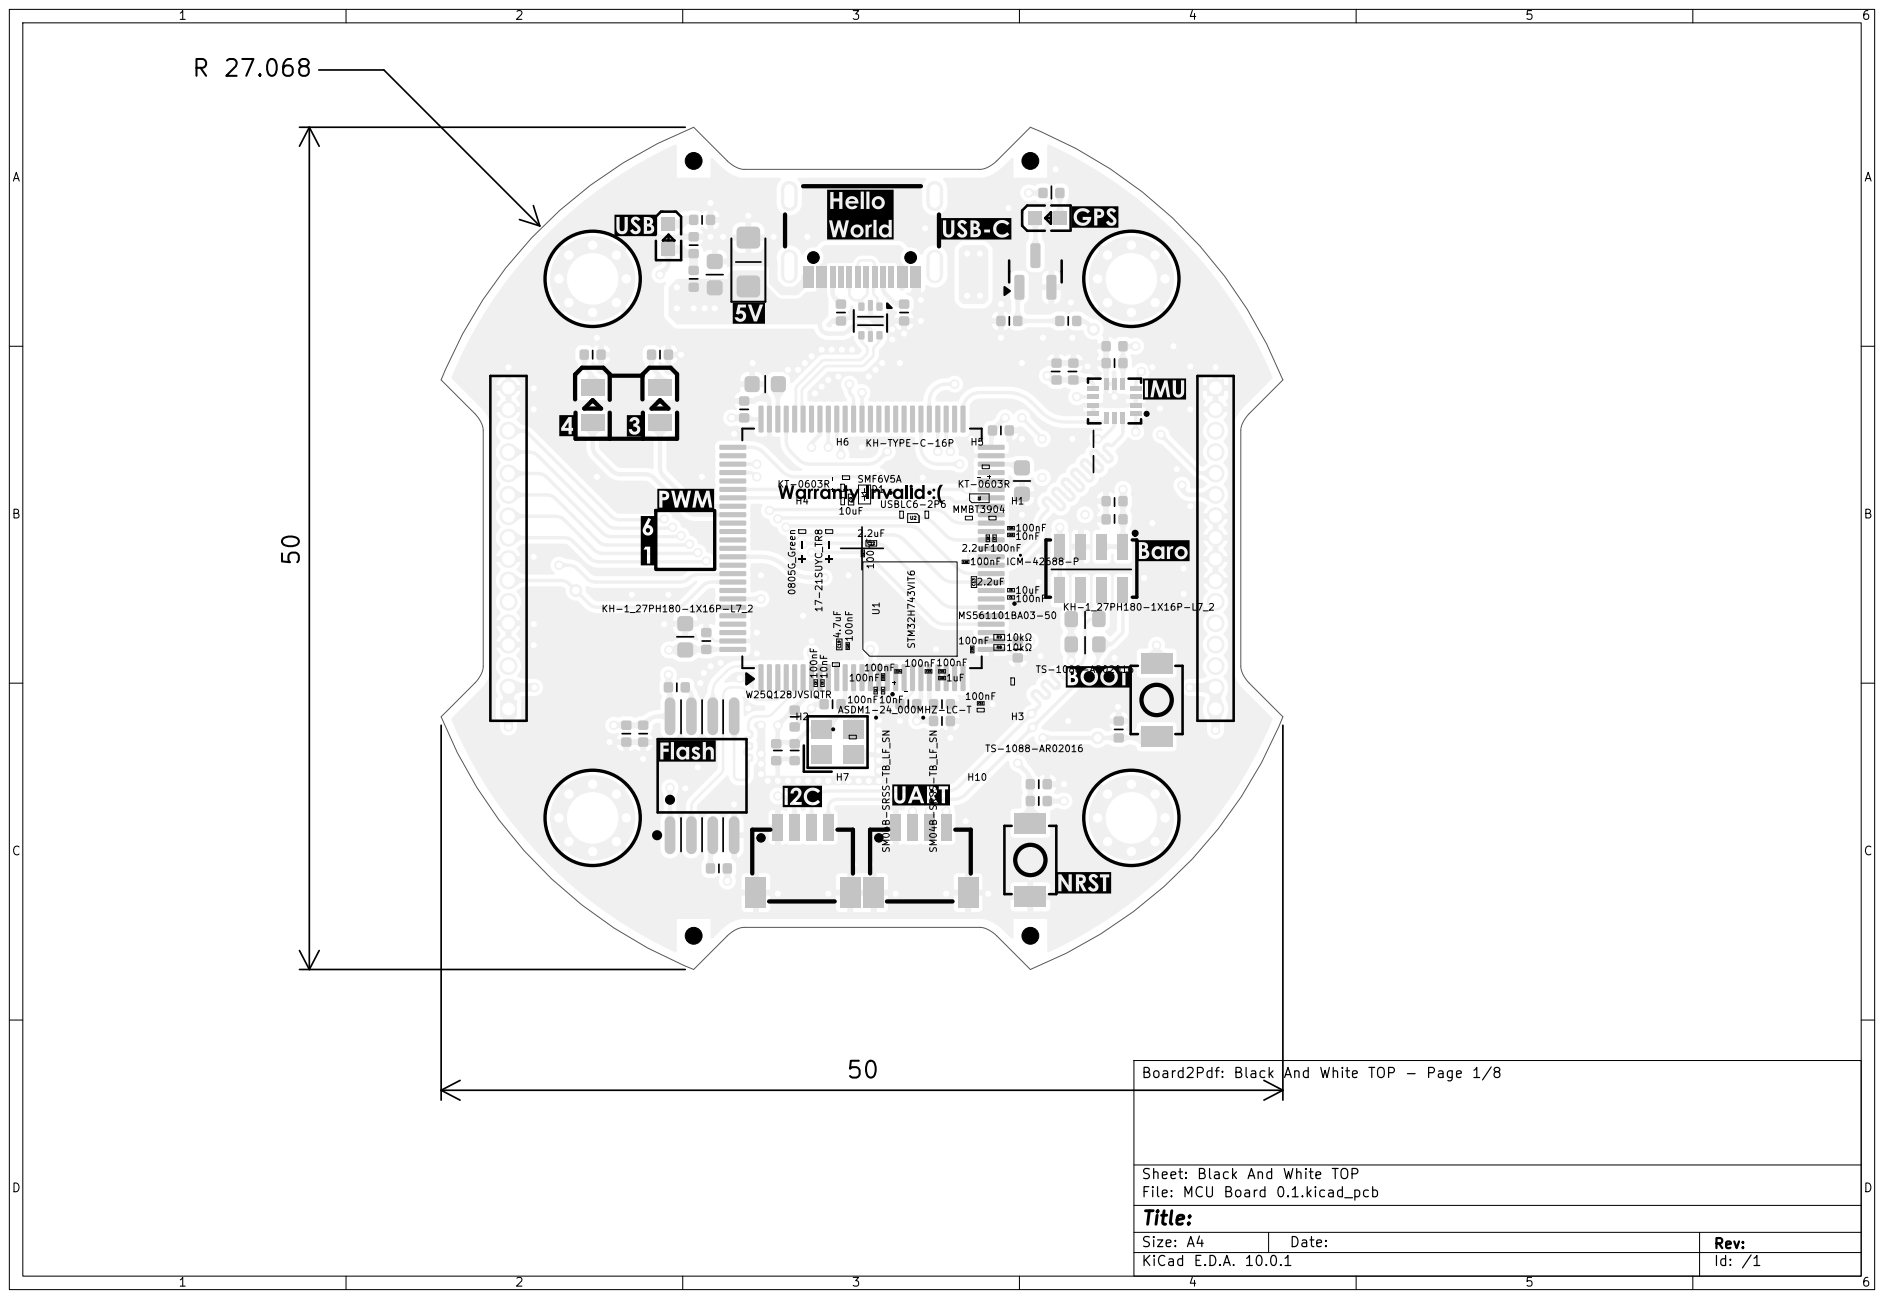
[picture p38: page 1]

Sheet: Black And White TOP
File: MCU Board 0.1.kicad_pcb
Title:
KiCad E.D.A. 10.0.1

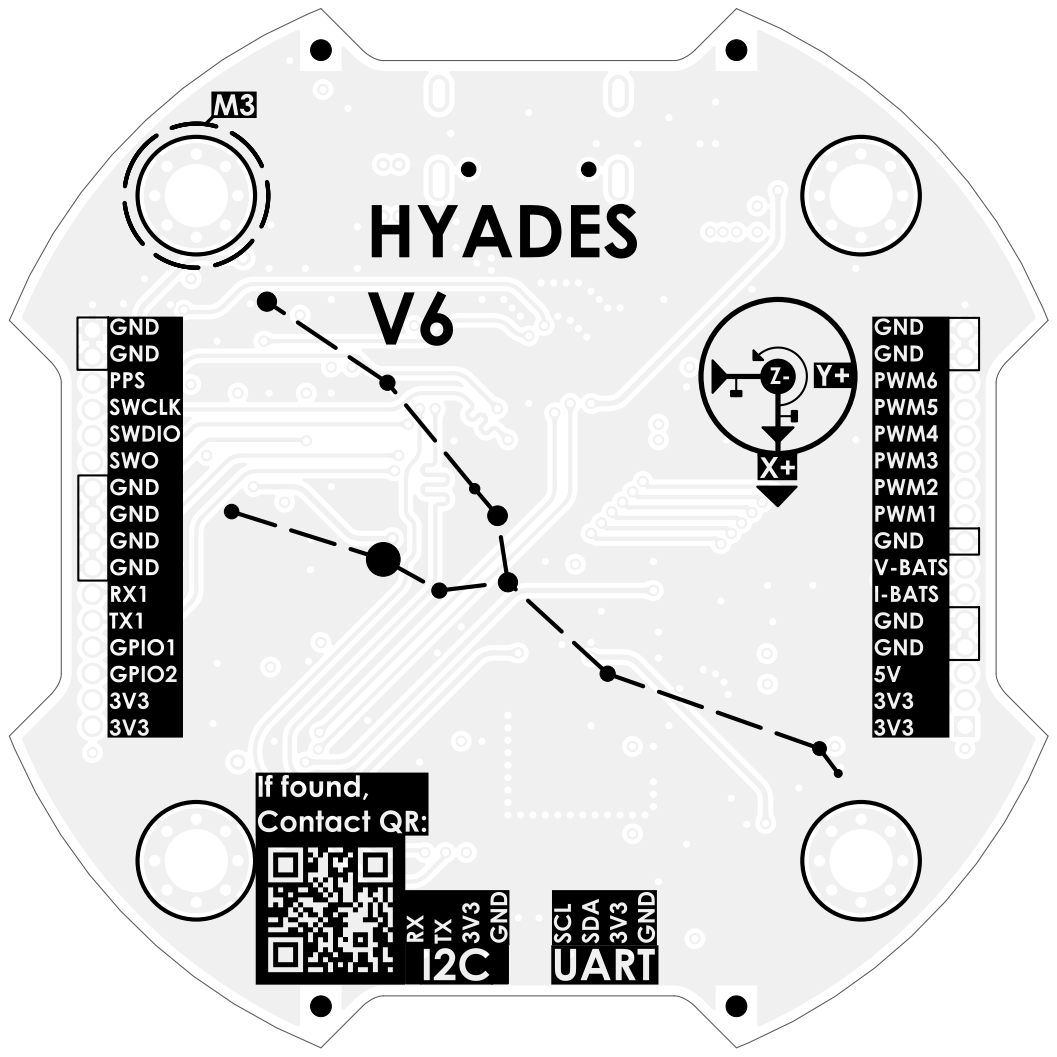
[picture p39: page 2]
6 ABCD; ABCD Date:

Board2Pdf: Black And White BOT - Page 2/8

Sheet: Black And White BOT
File: MCU Board 0.1.kicad_pcb
Title:

R 27.068

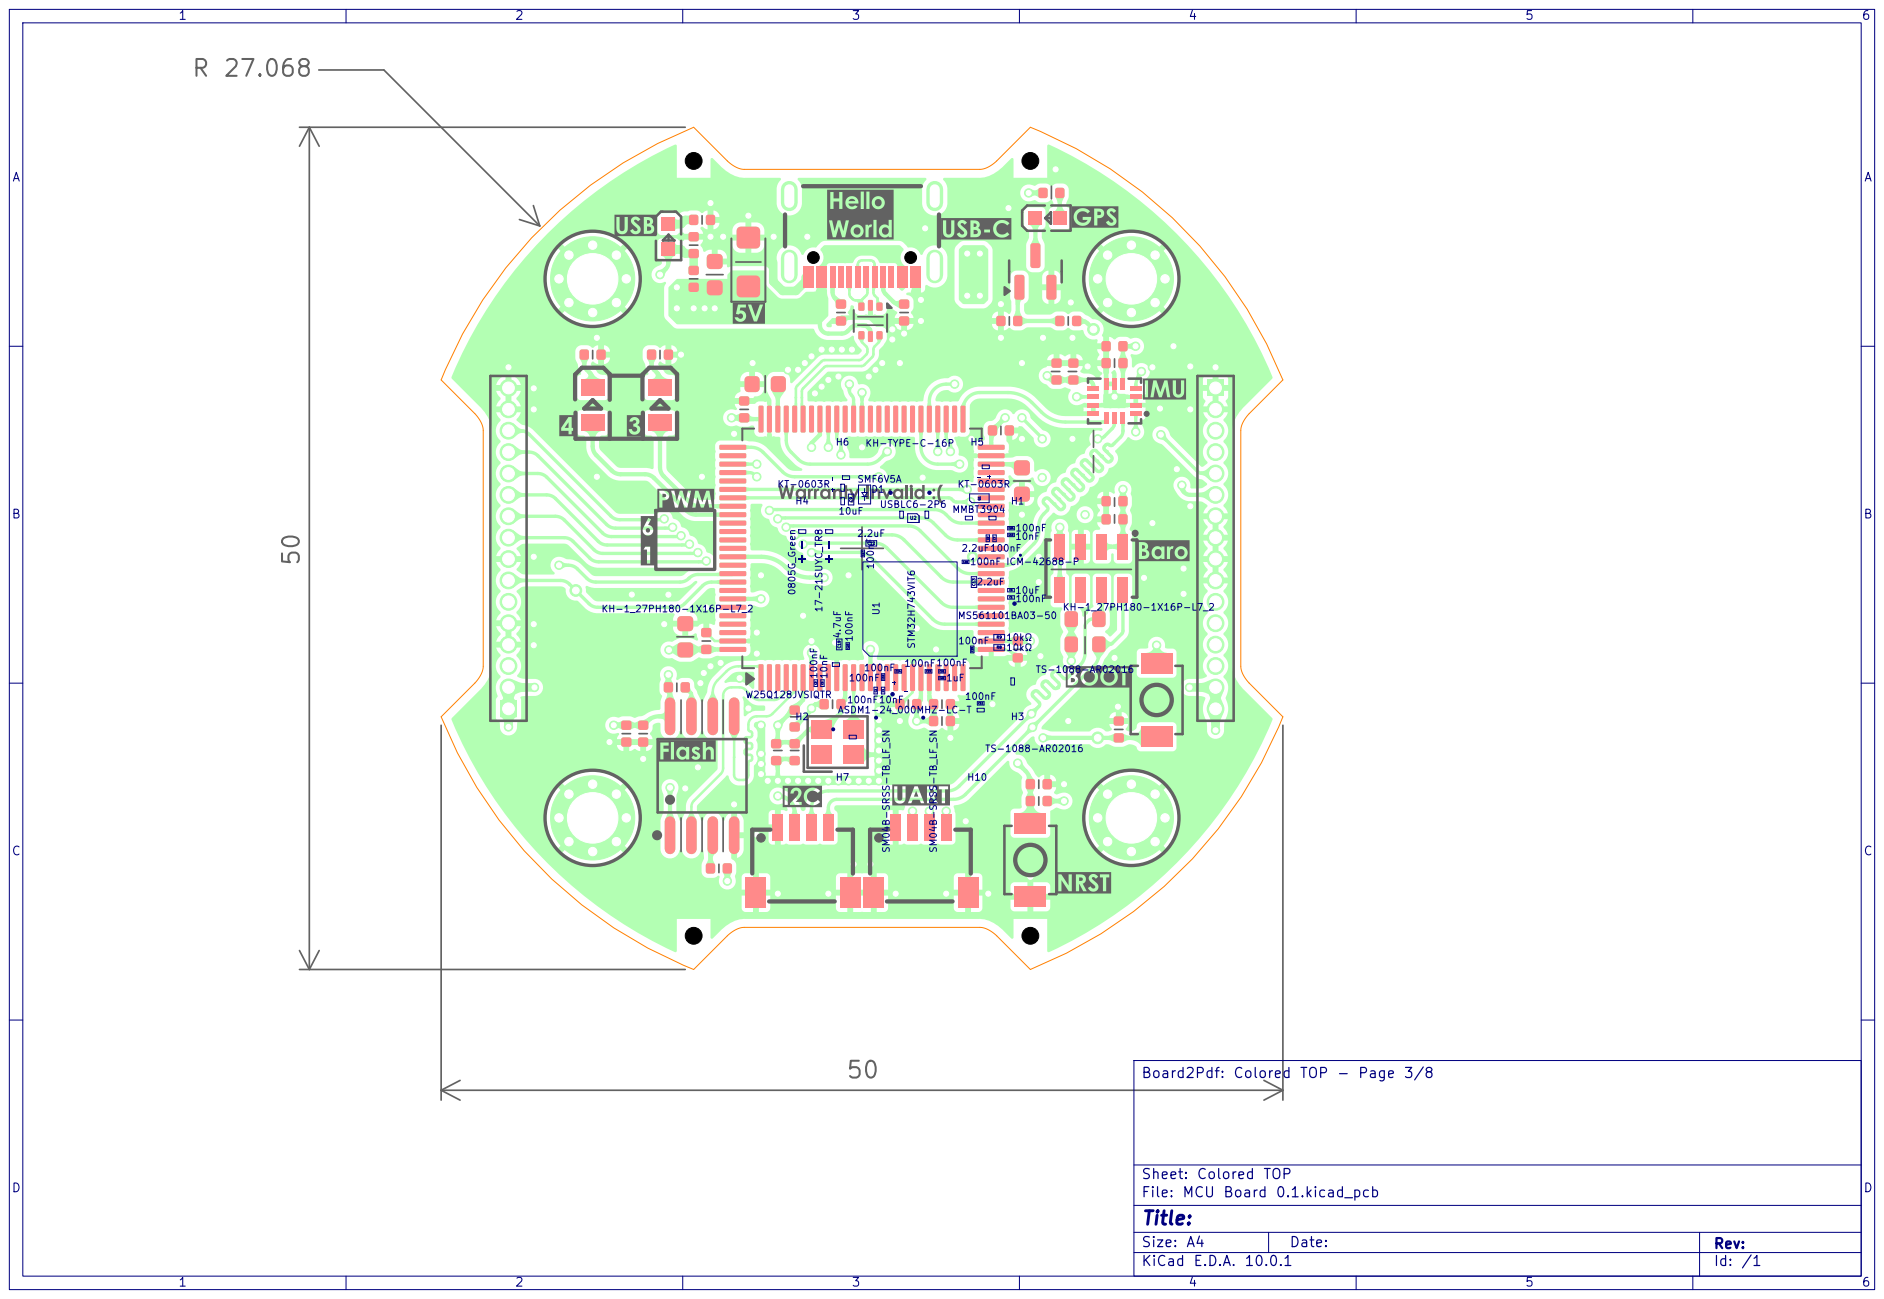
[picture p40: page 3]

R 27.068

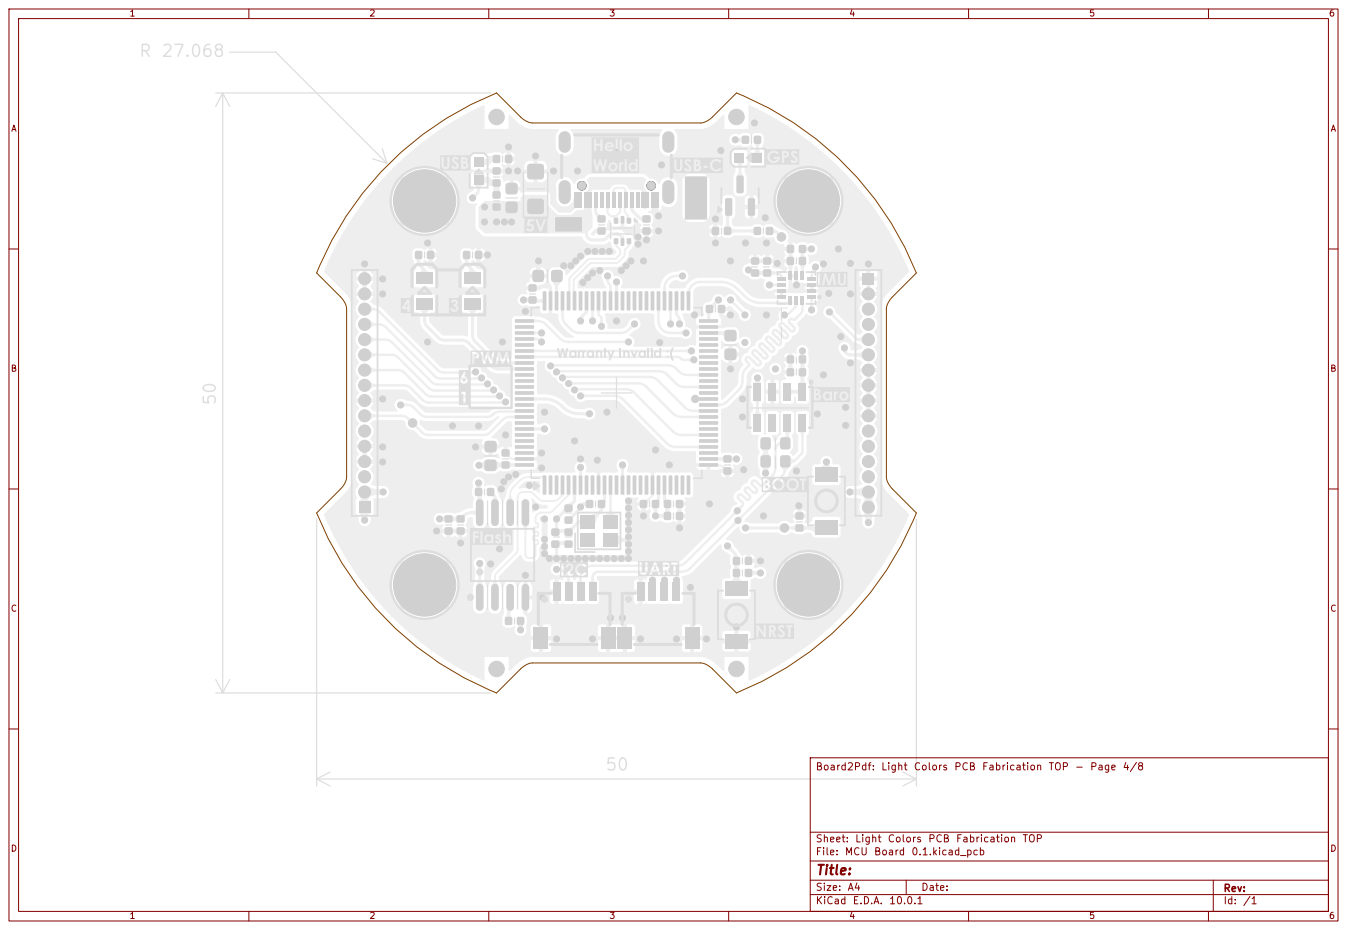
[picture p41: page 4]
6 ABCD; ABCD Date:

Board2Pdf: Light Colors PCB Fabrication TOP - Page 4/8

Sheet: Light Colors PCB Fabrication TOP
File: MCU Board 0.1.kicad_pcb
Title:

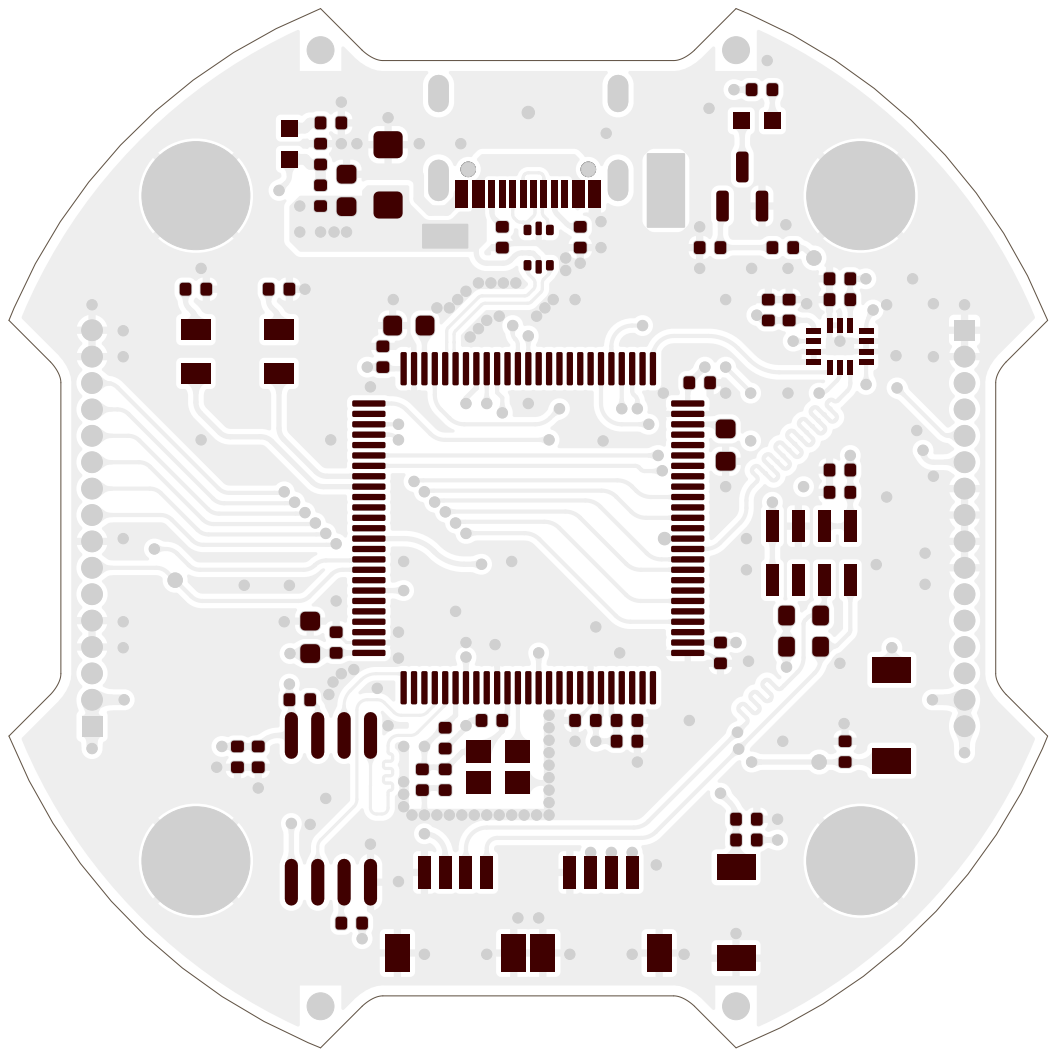
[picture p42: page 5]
6 ABCD; ABCD Date:

Board2Pdf: Light Colors PCB Paste TOP - Page 5/8

Sheet: Light Colors PCB Paste TOP
File: MCU Board 0.1.kicad_pcb
Title:

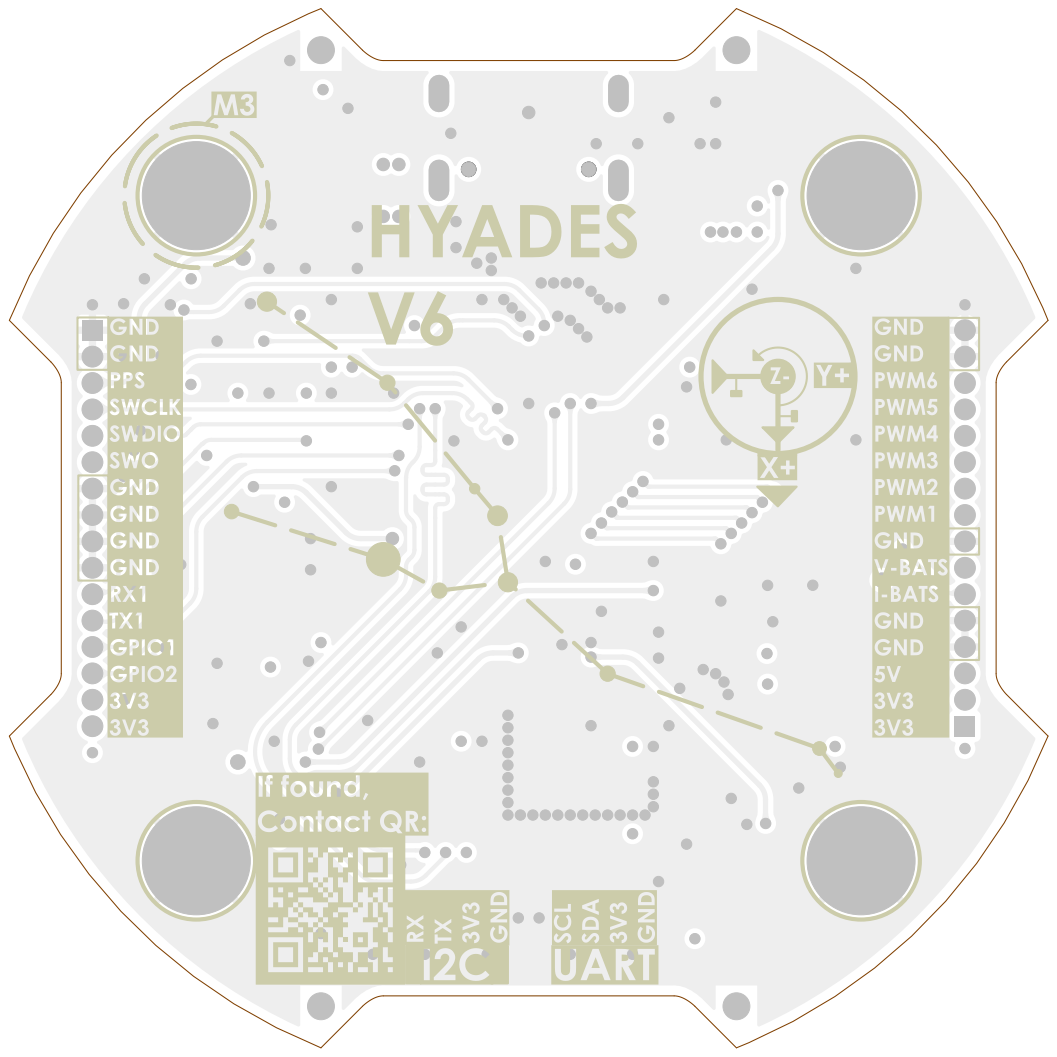
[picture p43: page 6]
6 ABCD; ABCD Date:

Board2Pdf: Light Colors Placement BOT - Page 6/8

Sheet: Light Colors Placement BOT
File: MCU Board 0.1.kicad_pcb
Title:

R 27.068

## SMF6V5A

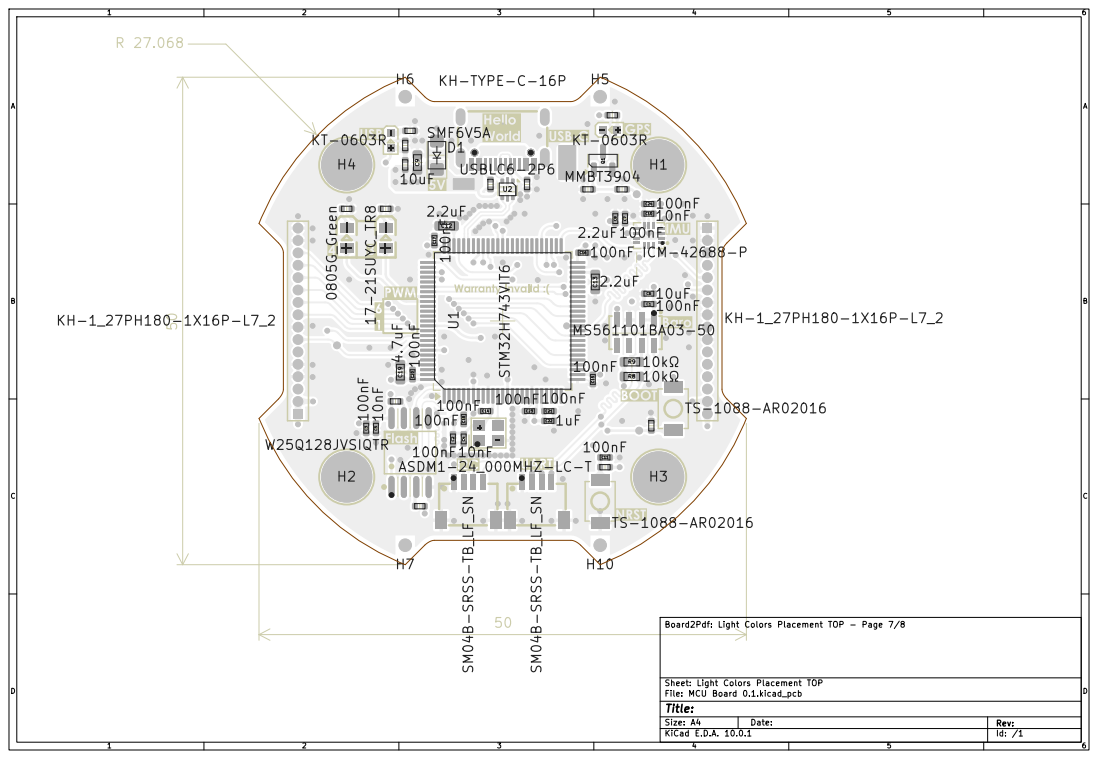
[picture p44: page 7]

Board2Pdf: Light Colors Placement TOP - Page 7/8

Sheet: Light Colors Placement TOP
File: MCU Board 0.1.kicad_pcb
Title:

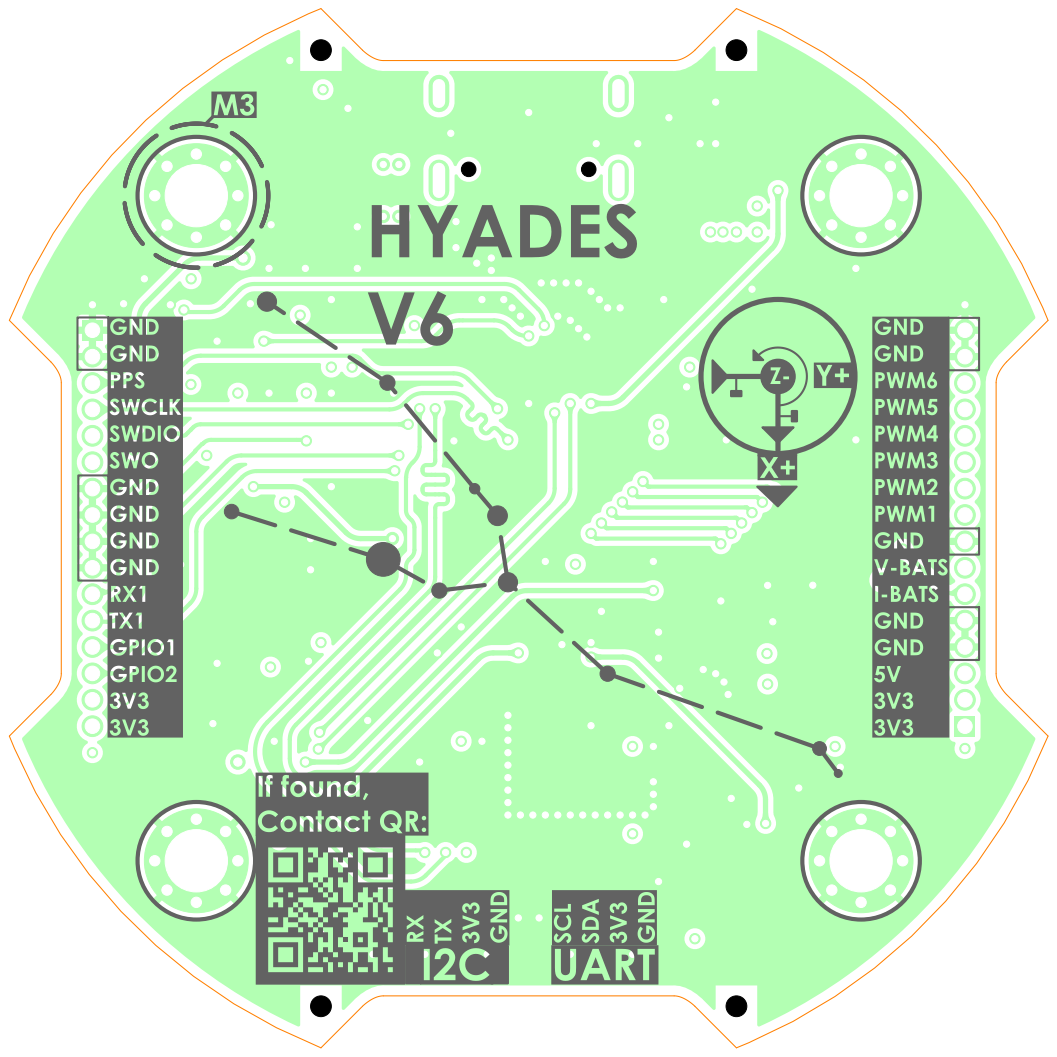
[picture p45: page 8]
6 ABCD; ABCD Date:

Board2Pdf: Colored BOT - Page 8/8

Sheet: Colored BOT
File: MCU Board 0.1.kicad_pcb
Title:

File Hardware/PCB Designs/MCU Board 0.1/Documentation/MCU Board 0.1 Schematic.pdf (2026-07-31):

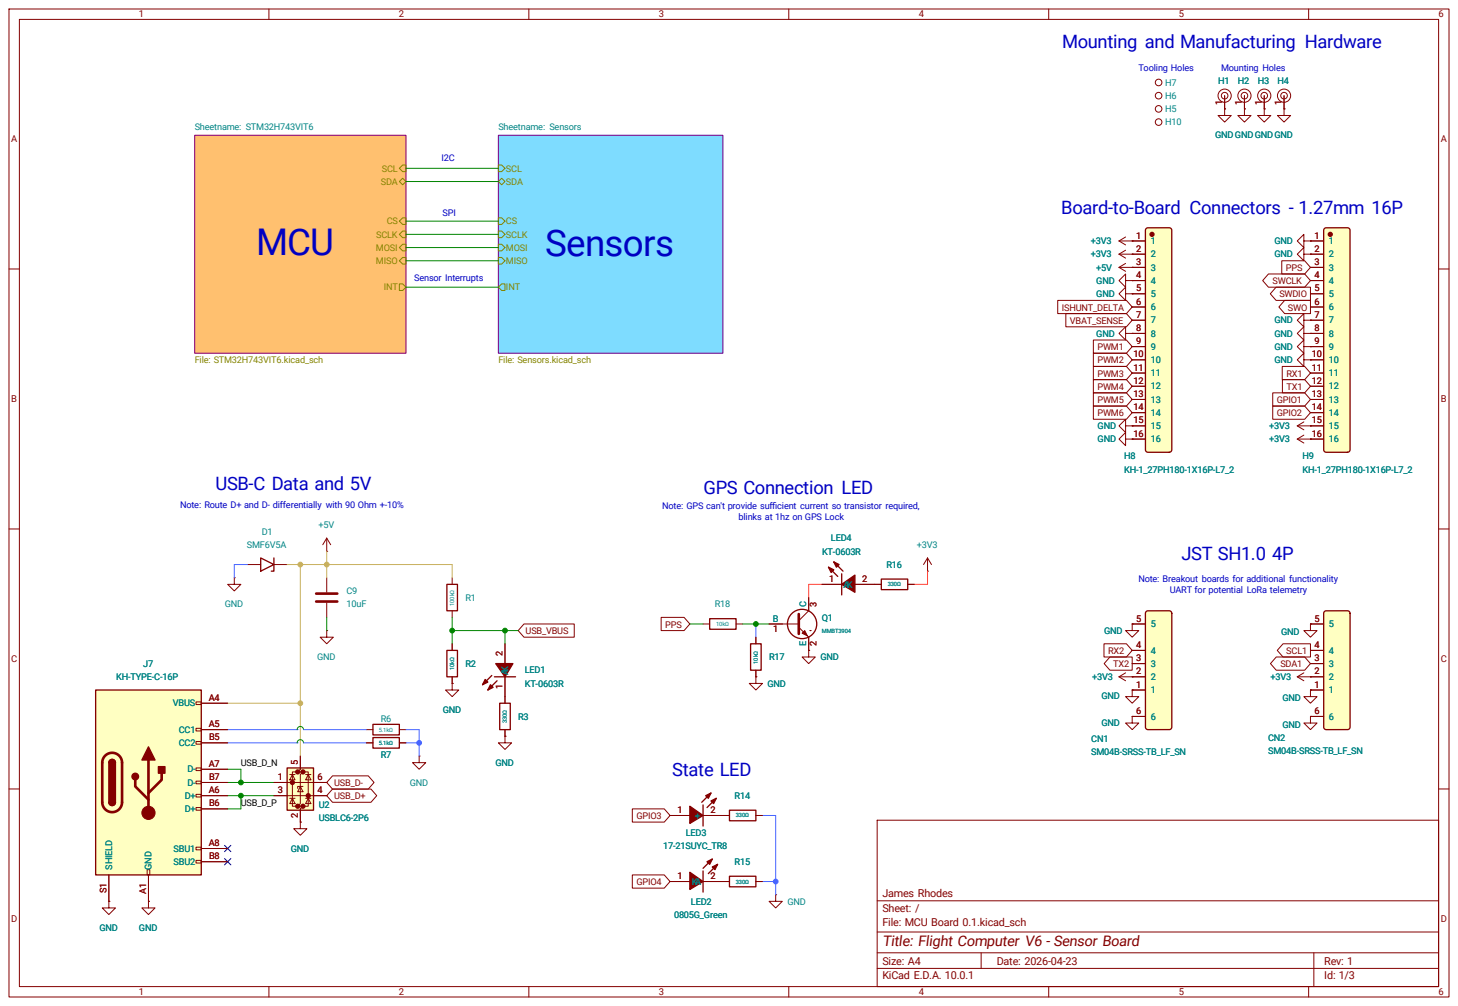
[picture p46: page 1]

16 16 GND GND GND GND H3

Note: Route D+ and D- differentially with 90 Ohm +-10%

File: MCU Board 0.1.kicad_sch
Title: Flight Computer V6 - Sensor Board

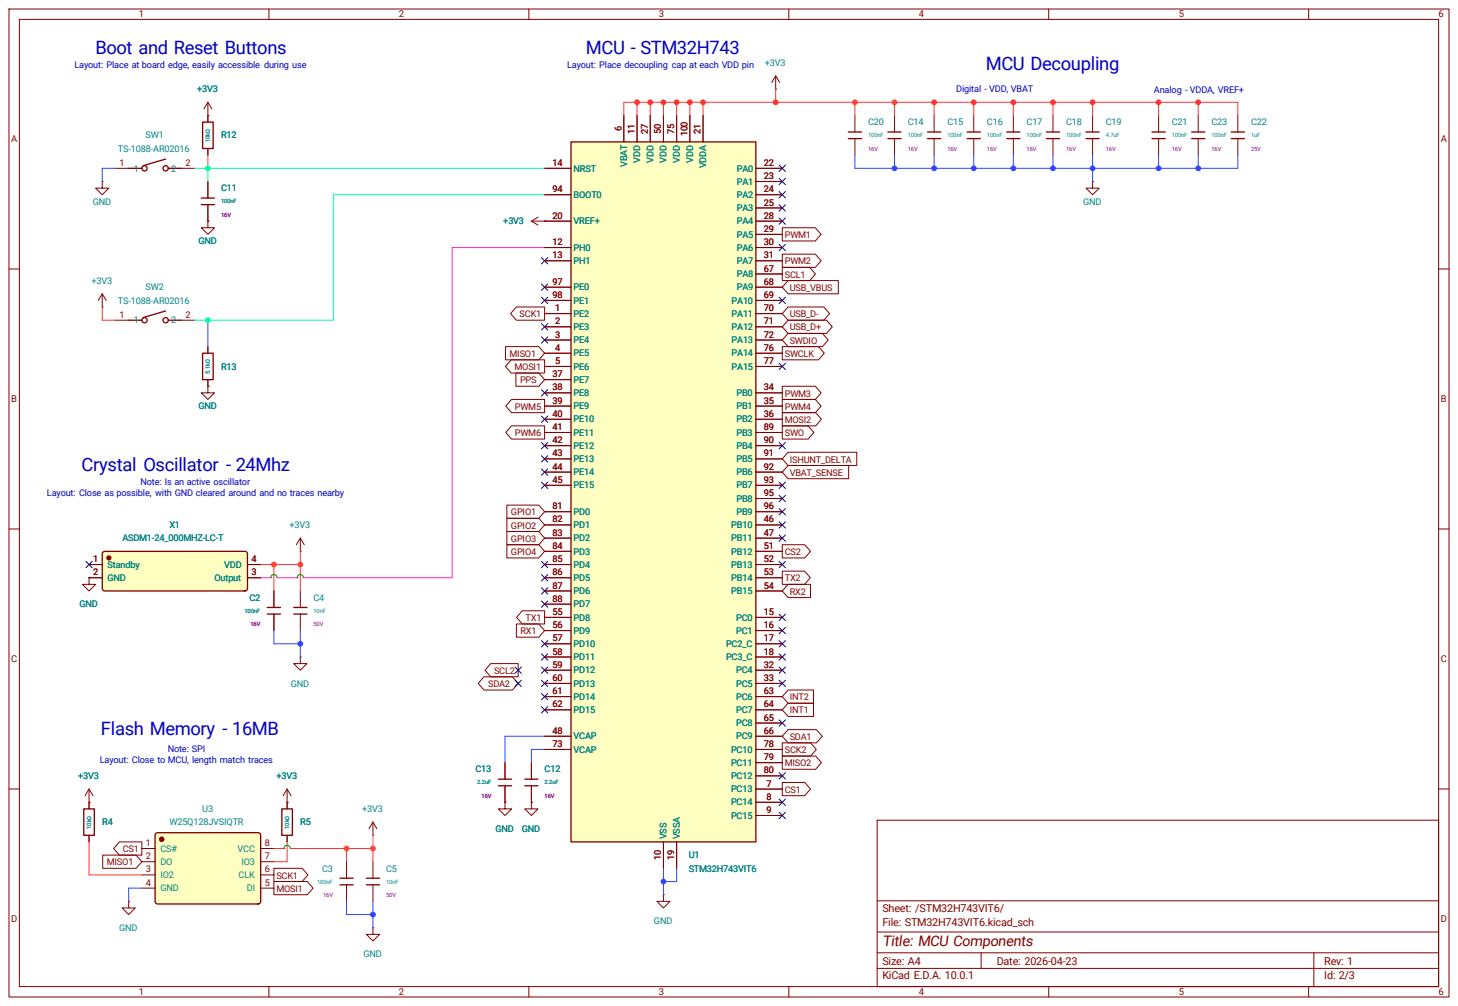
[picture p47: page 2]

Boot and Reset Buttons

Digital - VDD, VBAT MCU - STM32H743

Analog - VDDA, VREF+ MCU Decoupling

Note: SPI Layout: Close to MCU, length match traces Crystal Oscillator - 24Mhz

Note: Is an active oscillator Layout: Close as possible, with GND cleared around and no traces nearby

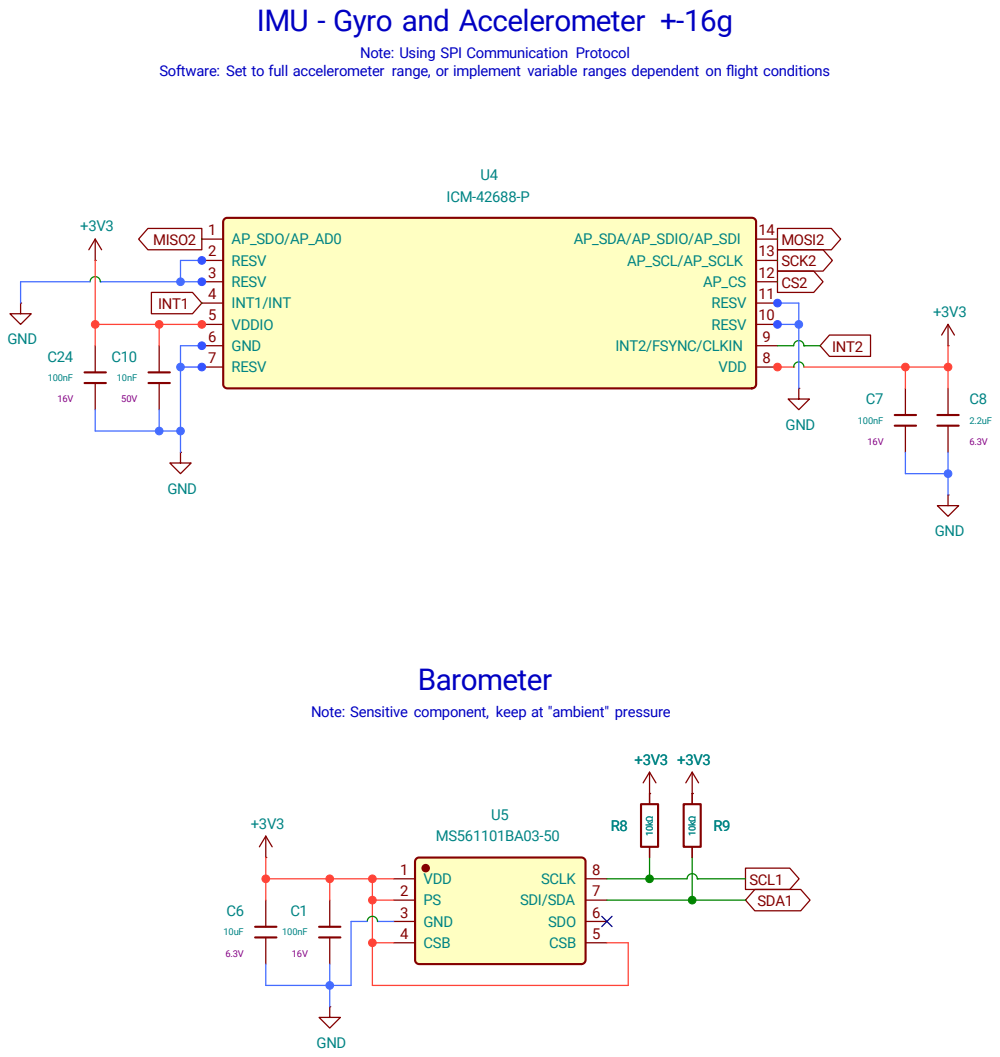
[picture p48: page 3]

Note: Using SPI Communication Protocol Software: Set to full accelerometer range, or implement variable ranges dependent on flight conditions IMU - Gyro and Accelerometer +-16g

INT2/FSYNC/CLKIN 9 RESV 10 RESV 11 AP_CS 12 AP_SCL/AP_SCLK 13 AP_SDA/AP_SDIO/AP_SDI 14 U4

Note: Sensitive component, keep at "ambient" pressure Barometer

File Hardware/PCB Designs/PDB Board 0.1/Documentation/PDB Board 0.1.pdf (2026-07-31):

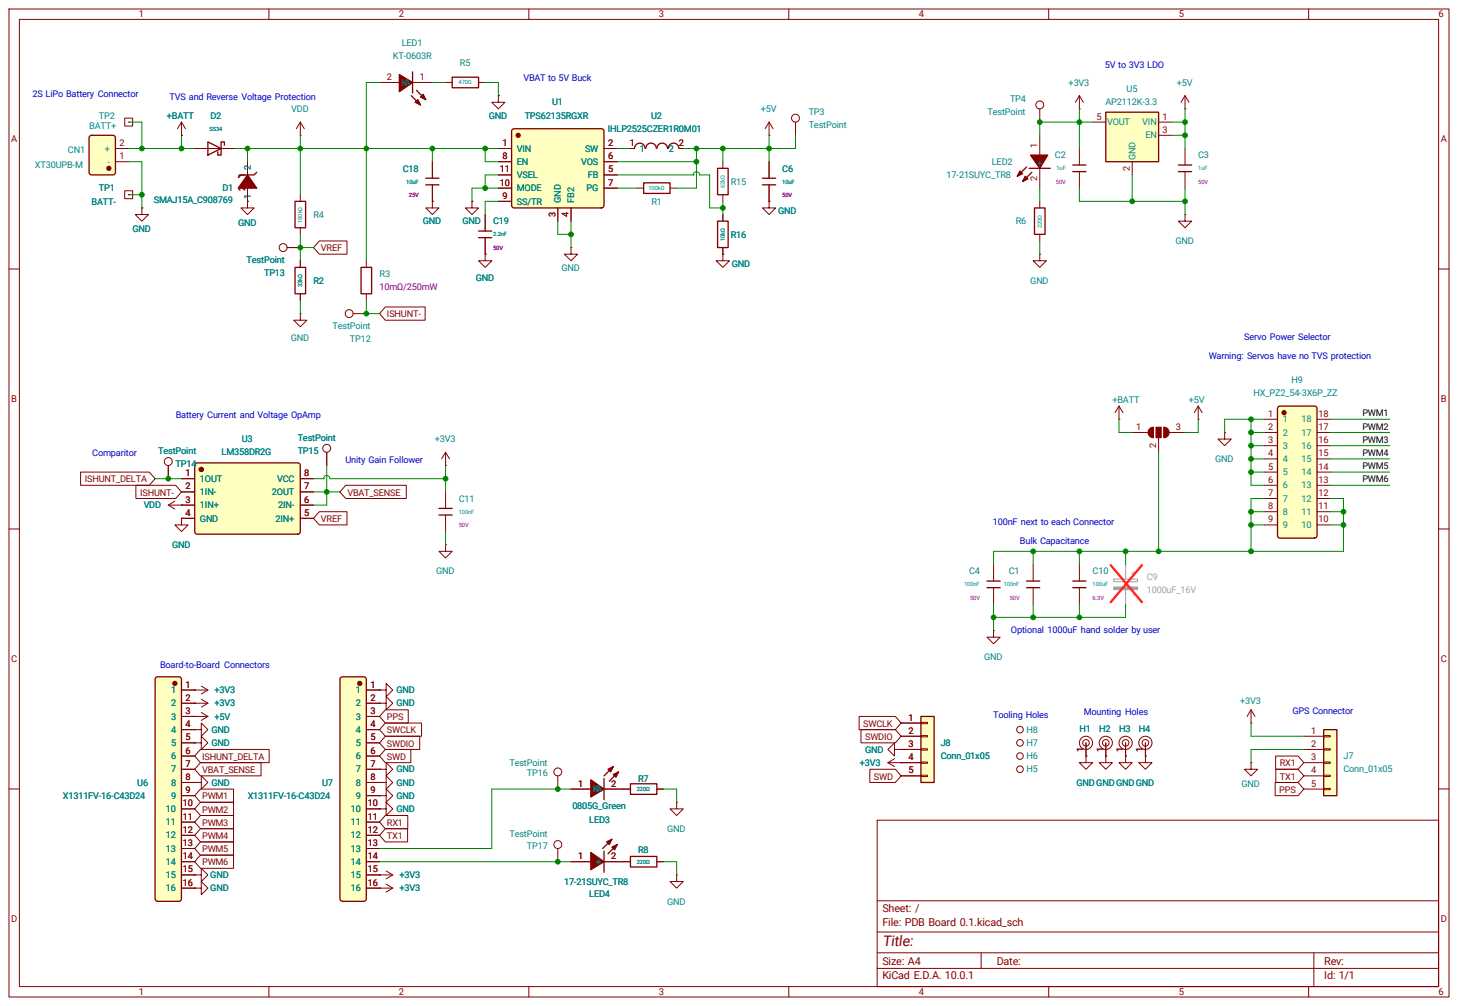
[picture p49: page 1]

1uF 50V +5V GND GND GND GND

Battery Current and Voltage OpAmp

PWM3 PWM4 PWM2 PWM1 PWM6 PWM5 Mounting Holes Optional 1000uF hand solder by user Bulk Capacitance

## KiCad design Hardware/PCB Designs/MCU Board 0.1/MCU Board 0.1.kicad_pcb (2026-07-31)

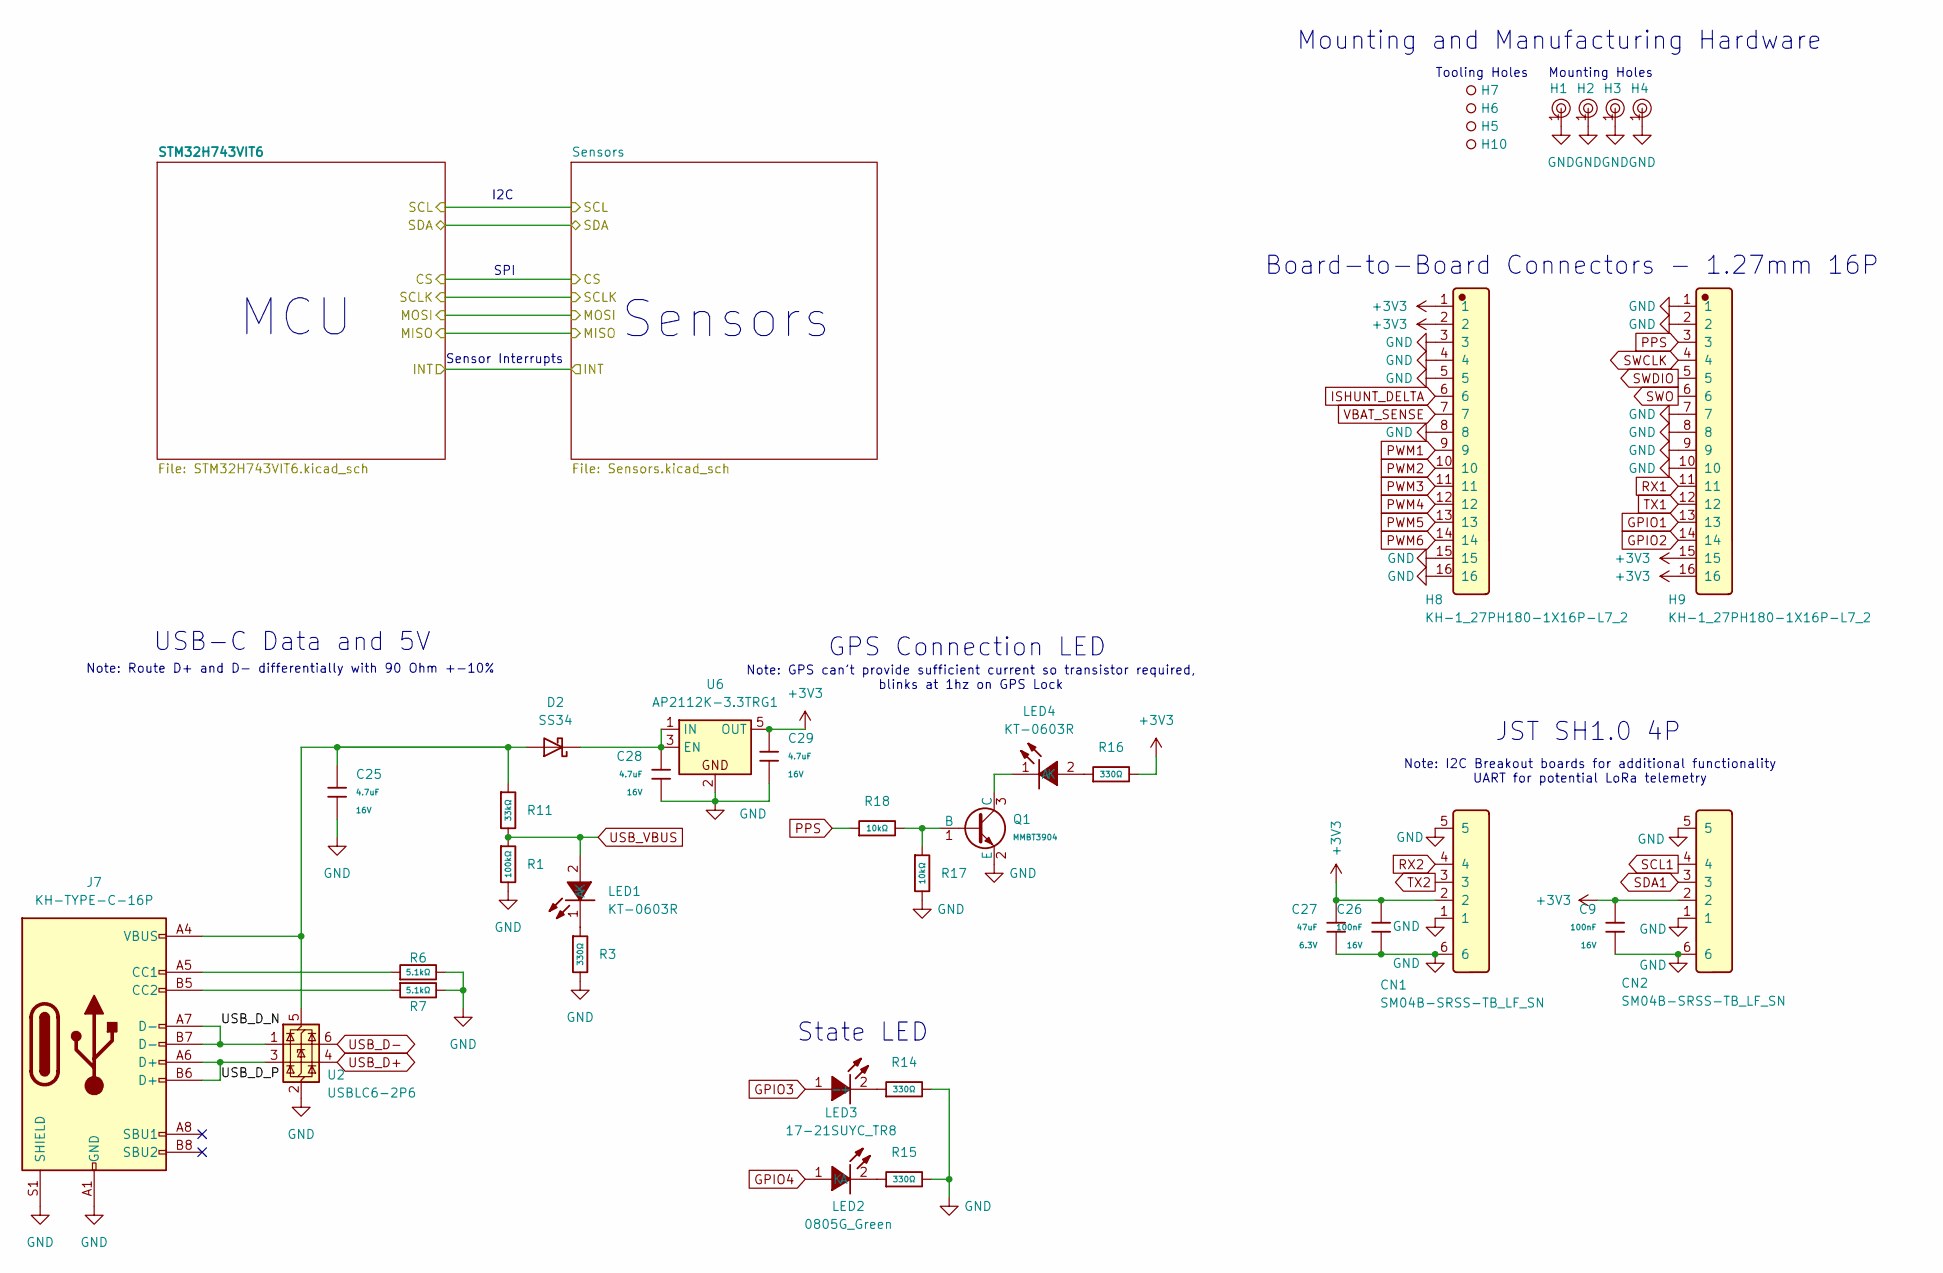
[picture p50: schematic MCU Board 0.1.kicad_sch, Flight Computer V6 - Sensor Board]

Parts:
C9, C26: 100nF; C_0402; Voltage Rated 16V; Tolerance ±10%; Part CL05B104KO5NNNC; LCSC C1525
C25, C28, C29: 4.7uF; C_0603; Voltage Rated 16V; Tolerance ±10%; Part CL10A475KO8NNNC; LCSC C19666
C27: 47uF; C_0805; Voltage Rated 6.3V; Tolerance ±20%; Part CL21A476MQYNNNE; LCSC C16780
CN1, CN2: SM04B-SRSS-TB_LF_SN; Manufacturer Part SM04B-SRSS-TB(LF)(SN); LCSC C160404
D2: SS34; D_SMA
H1, H2, H3, H4: Hole, 3mm
H5, H6, H7, H10: Hole_Tooling_JLCPCB
H8, H9: KH-1_27PH180-1X16P-L7_2; Manufacturer Part KH-1.27PH180-1X16P-L7.2; LCSC C2938407
J7: KH-TYPE-C-16P
LED1, LED4: KT-0603R; Manufacturer Part KT-0603R; LCSC C2286
LED2: 0805G_Green; Manufacturer Part KT-0805G; LCSC C2297
LED3: 17-21SUYC_TR8; Manufacturer Part KT-0805黄灯; LCSC C2296
Q1: MMBT3904; Q_SOT-23; Part MMBT3904; LCSC C7420353
R1: 100kΩ; R_0402; Overload Voltage (Max) 50V; Tolerance ±1%; Part 0402WGF1003TCE; LCSC C25741
R3, R14, R15, R16: 330Ω; R_0402; Overload Voltage (Max) 50V; Tolerance ±1%; Part 0402WGF3300TCE; LCSC C25104
R6, R7: 5.1kΩ; R_0402; Overload Voltage (Max) 50V; Tolerance ±1%; Part 0402WGF5101TCE; LCSC C25905
R11: 33kΩ; R_0402; Overload Voltage (Max) 50V; Tolerance ±1%; Part 0402WGF3302TCE; LCSC C25779
R17, R18: 10kΩ; R_0402; Overload Voltage (Max) 50V; Tolerance ±1%; Part 0402WGF1002TCE; LCSC C25744
U2: USBLC6-2P6; SOT-666
U6: AP2112K-3.3TRG1; SOT-23-5

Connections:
+3V3: C9.1, C26.1, C27.1, C29.1, CN1.2, CN2.2, H8.1, H8.2, H9.15, H9.16, R16.2, U6.5 (OUT); also elsewhere on the board
/USB_D_N: J7.A7 (D-), J7.B7 (D-), U2.1 (I/O1)
/USB_D_P: J7.A6 (D+), J7.B6 (D+), U2.3 (I/O2)
GND: C9.2, C25.2, C26.2, C27.2, C28.2, C29.2, CN1.1, CN1.5, CN1.6, CN2.1, CN2.5, CN2.6, H1.1, H2.1, H3.1, H4.1, H8.3, H8.4, H8.5, H8.8, H8.15, H8.16, H9.1, H9.2, H9.7, H9.8, H9.9, H9.10, J7.A1 (GND), J7.A12 (GND), J7.B1 (GND), J7.B12 (GND), J7.S1 (SHIELD), Q1.2 (E), R1.2, R3.2, R6.2, R7.2, R14.2, R15.2, R17.2, U2.2 (GND), U6.2; also elsewhere on the board
GPIO1: H9.13; also elsewhere on the board
GPIO2: H9.14; also elsewhere on the board
GPIO3: LED3.1 (+); also elsewhere on the board
GPIO4: LED2.1 (A); also elsewhere on the board
ISHUNT_DELTA: H8.6; also elsewhere on the board
unnamed: C25.1, D2.2 (A), J7.A4 (VBUS), J7.A9 (VBUS), J7.B4 (VBUS), J7.B9 (VBUS), R11.1, U2.5 (VBUS)
unnamed: C28.1, D2.1 (K), U6.1 (IN), U6.3 (EN)
unnamed: J7.A5 (CC1), R6.1
unnamed: J7.B5 (CC2), R7.1
unnamed: LED1.1 (K), R3.1
unnamed: LED2.2 (K), R15.1
unnamed: LED3.2 (-), R14.1
unnamed: LED4.2 (A), R16.1
unnamed: LED4.1 (K), Q1.3 (C)
unnamed: Q1.1 (B), R17.1, R18.2
PPS: H9.3, R18.1; also elsewhere on the board
PWM1: H8.9; also elsewhere on the board
PWM2: H8.10; also elsewhere on the board
PWM3: H8.11; also elsewhere on the board
PWM4: H8.12; also elsewhere on the board
PWM5: H8.13; also elsewhere on the board
PWM6: H8.14; also elsewhere on the board
RX1: H9.11; also elsewhere on the board
RX2: CN1.4; also elsewhere on the board
SCL1: CN2.4; also elsewhere on the board
SDA1: CN2.3; also elsewhere on the board
SWCLK: H9.4; also elsewhere on the board
SWDIO: H9.5; also elsewhere on the board
SWO: H9.6; also elsewhere on the board
TX1: H9.12; also elsewhere on the board
TX2: CN1.3; also elsewhere on the board
USB_D+: U2.4 (I/O2); also elsewhere on the board
USB_D-: U2.6 (I/O1); also elsewhere on the board
USB_VBUS: LED1.2 (A), R1.1, R11.2; also elsewhere on the board
VBAT_SENSE: H8.7; also elsewhere on the board

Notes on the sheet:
Tooling Holes
Sensor Interrupts
Sensors
Board-to-Board Connectors - 1.27mm 16P
GPS Connection LED
State LED
USB-C Data and 5V
Note: Route D+ and D- differentially with 90 Ohm +-10%
Note: GPS can't provide sufficient current so transistor required, blinks at 1hz on GPS Lock
JST SH1.0 4P
Note: I2C Breakout boards for additional functionality UART for potential LoRa telemetry
SPI
I2C
Mounting and Manufacturing Hardware
Mounting Holes
MCU

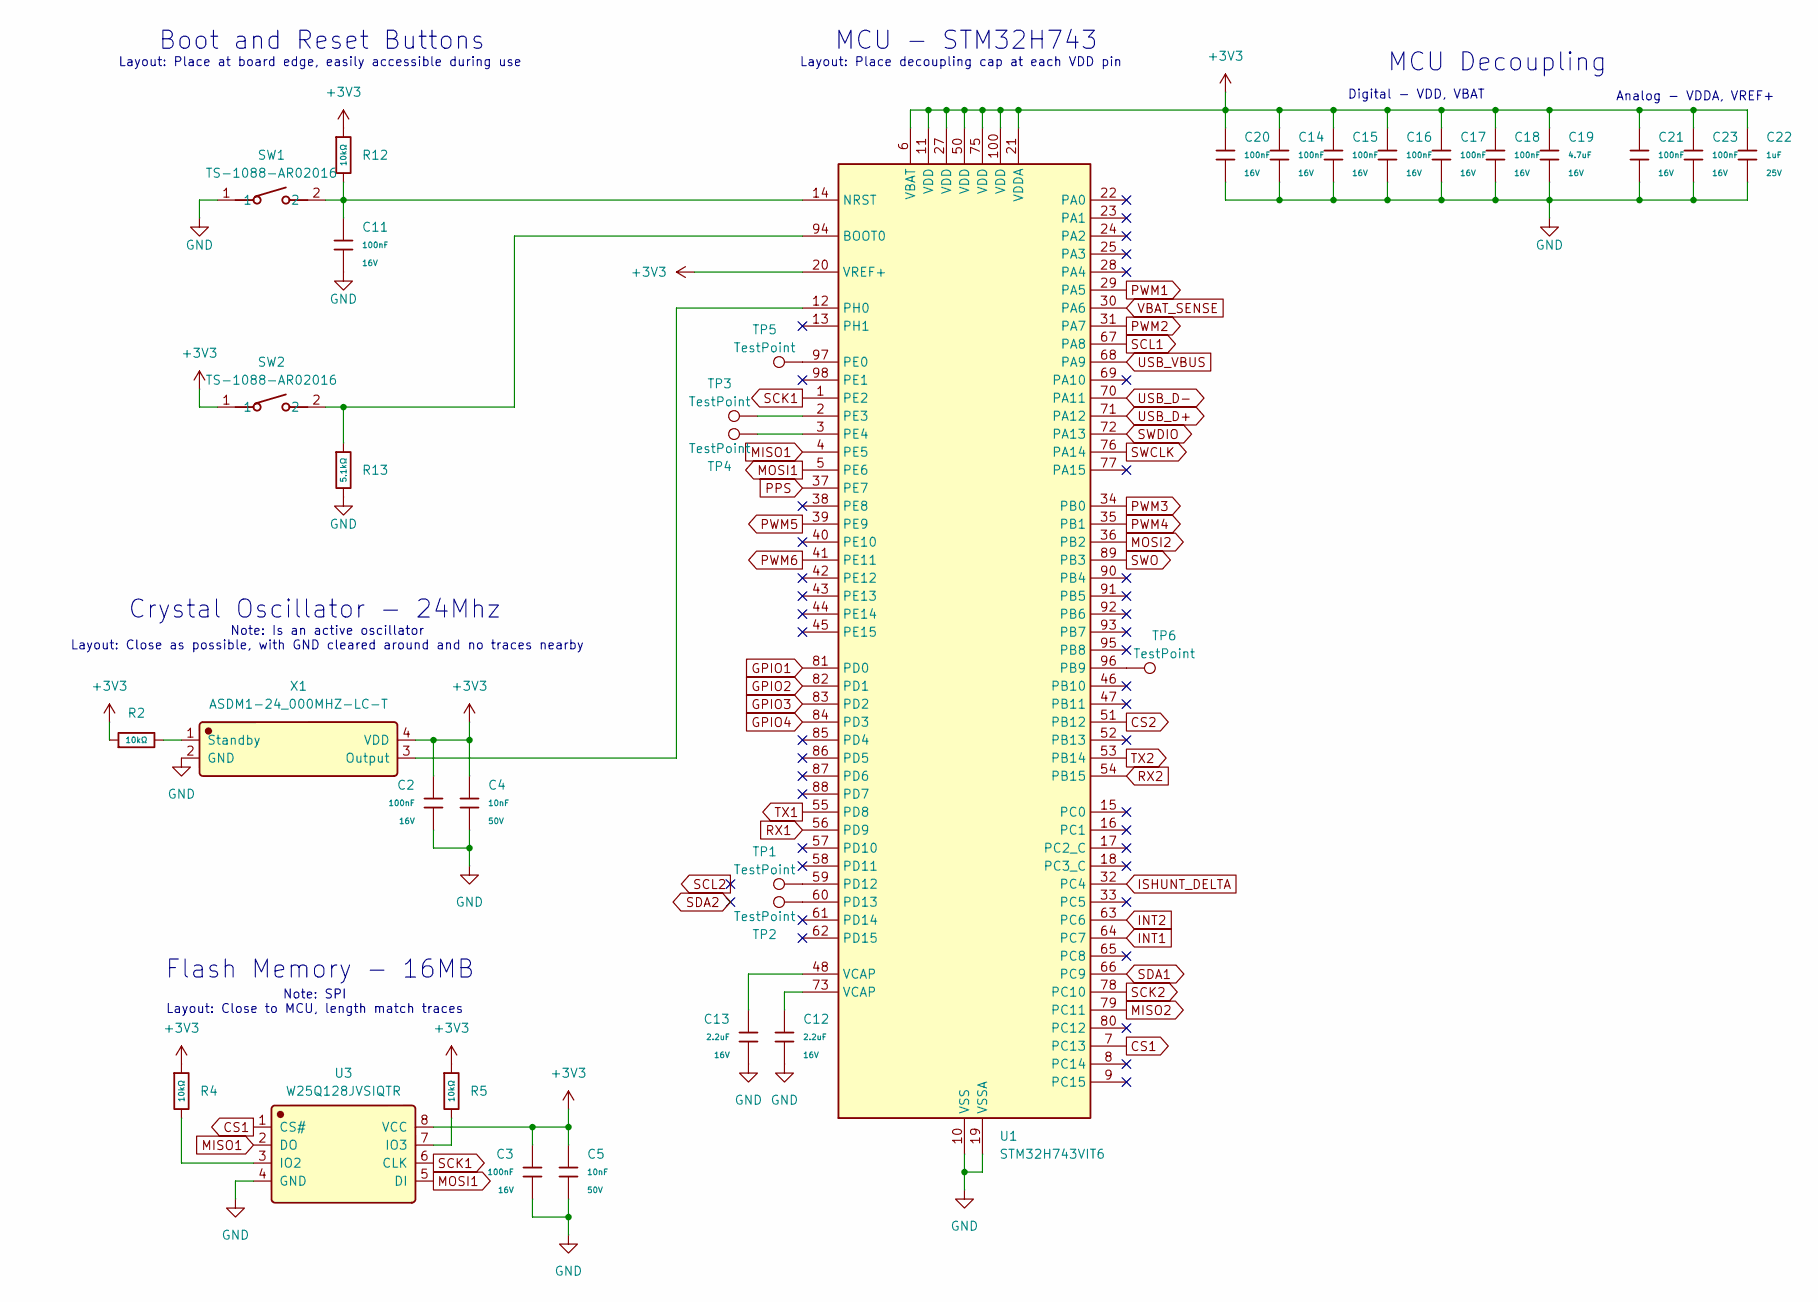
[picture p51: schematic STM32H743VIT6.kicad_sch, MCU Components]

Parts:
C2, C3, C11, C14, C15, C16, C17, C18, C20, C21, C23: 100nF; C_0402; Voltage Rated 16V; Tolerance ±10%; Part CL05B104KO5NNNC; LCSC C1525
C4, C5: 10nF; C_0402; Voltage Rated 50V; Tolerance ±10%; Part CL05B103KB5NNNC; LCSC C15195
C12, C13: 2.2uF; C_0603; Voltage Rated 16V; Tolerance ±10%; Part CL10A225KO8NNNC; LCSC C23630
C19: 4.7uF; C_0603; Voltage Rated 16V; Tolerance ±10%; Part CL10A475KO8NNNC; LCSC C19666
C22: 1uF; C_0402; Voltage Rated 25V; Tolerance ±10%; Part CL05A105KA5NQNC; LCSC C52923
R2: 10kΩ; R_0603; Overload Voltage (Max) 75V; Tolerance ±1%; Part 0603WAF1002T5E; LCSC C25804
R4, R5, R12: 10kΩ; R_0402; Overload Voltage (Max) 50V; Tolerance ±1%; Part 0402WGF1002TCE; LCSC C25744
R13: 5.1kΩ; R_0402; Overload Voltage (Max) 50V; Tolerance ±1%; Part 0402WGF5101TCE; LCSC C25905
SW1, SW2: TS-1088-AR02016; Manufacturer Part TS-1088-AR02016; LCSC C720477
TP1, TP2, TP3, TP4, TP5, TP6: TestPoint; TestPoint_Pad_1.5x1.5mm
U1: STM32H743VIT6; LQFP-100_14x14mm_P0.5mm
U3: W25Q128JVSIQTR; Manufacturer Part W25Q128JVSIQ; LCSC C97521
X1: ASDM1-24_000MHZ-LC-T; Manufacturer Part ASDM1-24.000MHZ-LC-T; LCSC C1987235

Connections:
+3V3: C2.1, C3.1, C4.1, C5.1, C14.1, C15.1, C16.1, C17.1, C18.1, C19.1, C20.1, C21.1, C22.1, C23.1, R2.1, R4.1, R5.1, R12.1, SW2.1, U1.6 (VBAT), U1.11 (VDD), U1.20 (VREF+), U1.21 (VDDA), U1.27 (VDD), U1.50 (VDD), U1.75 (VDD), U1.100 (VDD), U3.8 (VCC), X1.4 (VDD); also elsewhere on the board
CS1: U1.7 (PC13), U3.1 (CS#)
CS2: U1.51 (PB12); also elsewhere on the board
GND: C2.2, C3.2, C4.2, C5.2, C11.2, C12.2, C13.2, C14.2, C15.2, C16.2, C17.2, C18.2, C19.2, C20.2, C21.2, C22.2, C23.2, R13.2, SW1.1, U1.10 (VSS), U1.19 (VSSA), U1.26 (VSS), U1.49 (VSS), U1.74 (VSS), U1.99 (VSS), U3.4 (GND), X1.2 (GND); also elsewhere on the board
GPIO1: U1.81 (PD0); also elsewhere on the board
GPIO2: U1.82 (PD1); also elsewhere on the board
GPIO3: U1.83 (PD2); also elsewhere on the board
GPIO4: U1.84 (PD3); also elsewhere on the board
INT1: U1.64 (PC7); also elsewhere on the board
INT2: U1.63 (PC6); also elsewhere on the board
ISHUNT_DELTA: U1.32 (PC4); also elsewhere on the board
MISO1: U1.4 (PE5), U3.2 (DO)
MISO2: U1.79 (PC11); also elsewhere on the board
MOSI1: U1.5 (PE6), U3.5 (DI)
MOSI2: U1.36 (PB2); also elsewhere on the board
unnamed: C12.1, U1.73 (VCAP)
unnamed: C13.1, U1.48 (VCAP)
unnamed: R13.1, SW2.2, U1.94 (BOOT0)
unnamed: C11.1, R12.2, SW1.2, U1.14 (NRST)
unnamed: TP6.1 (1_1), U1.96 (PB9)
unnamed: TP1.1 (1_1), U1.59 (PD12)
unnamed: TP2.1 (1_1), U1.60 (PD13)
unnamed: TP5.1 (1_1), U1.97 (PE0)
unnamed: TP3.1 (1_1), U1.2 (PE3)
unnamed: TP4.1 (1_1), U1.3 (PE4)
unnamed: U1.12 (PH0), X1.3 (Output)
unnamed: R4.2, U3.3 (IO2)
unnamed: R5.2, U3.7 (IO3)
unnamed: R2.2, X1.1 (Standby)
PPS: U1.37 (PE7); also elsewhere on the board
PWM1: U1.29 (PA5); also elsewhere on the board
PWM2: U1.31 (PA7); also elsewhere on the board
PWM3: U1.34 (PB0); also elsewhere on the board
PWM4: U1.35 (PB1); also elsewhere on the board
PWM5: U1.39 (PE9); also elsewhere on the board
PWM6: U1.41 (PE11); also elsewhere on the board
RX1: U1.56 (PD9); also elsewhere on the board
RX2: U1.54 (PB15); also elsewhere on the board
SCK1: U1.1 (PE2), U3.6 (CLK)
SCK2: U1.78 (PC10); also elsewhere on the board
SCL1: U1.67 (PA8); also elsewhere on the board
SDA1: U1.66 (PC9); also elsewhere on the board
SWCLK: U1.76 (PA14); also elsewhere on the board
SWDIO: U1.72 (PA13); also elsewhere on the board
SWO: U1.89 (PB3); also elsewhere on the board
TX1: U1.55 (PD8); also elsewhere on the board
TX2: U1.53 (PB14); also elsewhere on the board
USB_D+: U1.71 (PA12); also elsewhere on the board
USB_D-: U1.70 (PA11); also elsewhere on the board
USB_VBUS: U1.68 (PA9); also elsewhere on the board
VBAT_SENSE: U1.30 (PA6); also elsewhere on the board

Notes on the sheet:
Note: SPI Layout: Close to MCU, length match traces
Flash Memory - 16MB
Crystal Oscillator - 24Mhz
MCU Decoupling
Layout: Place decoupling cap at each VDD pin
Boot and Reset Buttons
Analog - VDDA, VREF+
MCU - STM32H743
Digital - VDD, VBAT
Note: Is an active oscillator Layout: Close as possible, with GND cleared around and no traces nearby
Layout: Place at board edge, easily accessible during use

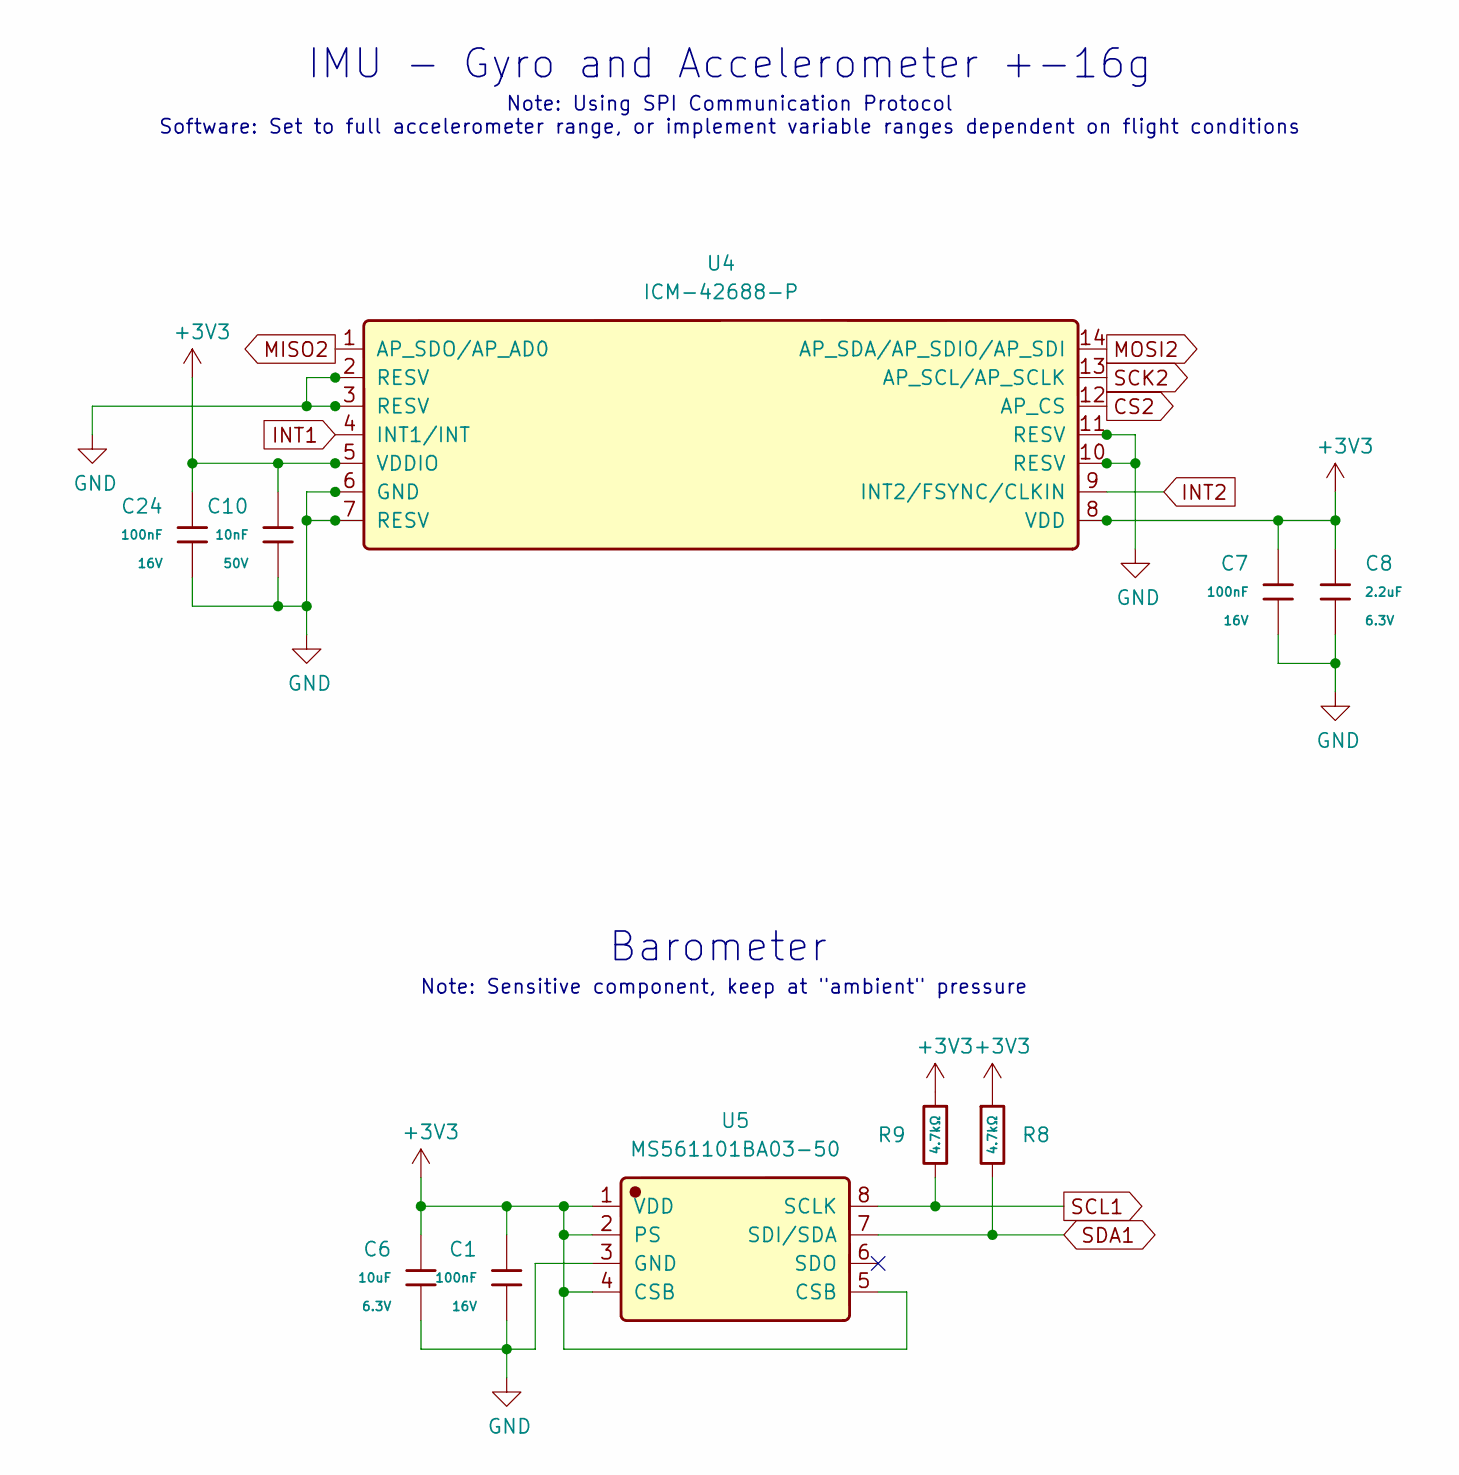
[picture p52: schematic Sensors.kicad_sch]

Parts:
C1, C7, C24: 100nF; C_0402; Voltage Rated 16V; Tolerance ±10%; Part CL05B104KO5NNNC; LCSC C1525
C6: 10uF; C_0402; Voltage Rated 6.3V; Tolerance ±20%; Part CL05A106MQ5NUNC; LCSC C15525
C8: 2.2uF; C_0402; Voltage Rated 6.3V; Tolerance ±20%; Part CL05A225MQ5NSNC; LCSC C12530
C10: 10nF; C_0402; Voltage Rated 50V; Tolerance ±10%; Part CL05B103KB5NNNC; LCSC C15195
R8, R9: 4.7kΩ; R_0603; Overload Voltage (Max) 75V; Tolerance ±1%; Part 0603WAF4701T5E; LCSC C23162
U4: ICM-42688-P; Manufacturer Part ICM-42688-P; LCSC C1850418
U5: MS561101BA03-50; Manufacturer Part MS561101BA03-50; LCSC C15639

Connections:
+3V3: C1.1, C6.1, C7.1, C8.1, C10.1, C24.1, R8.1, R9.1, U4.5 (VDDIO), U4.8 (VDD), U5.1 (VDD), U5.2 (PS), U5.4 (CSB), U5.5 (CSB); also elsewhere on the board
CS2: U4.12 (AP_CS); also elsewhere on the board
GND: C1.2, C6.2, C7.2, C8.2, C10.2, C24.2, U4.2 (RESV), U4.3 (RESV), U4.6 (GND), U4.7 (RESV), U4.10 (RESV), U4.11 (RESV), U5.3 (GND); also elsewhere on the board
INT1: U4.4 (INT1/INT); also elsewhere on the board
INT2: U4.9 (INT2/FSYNC/CLKIN); also elsewhere on the board
MISO2: U4.1 (AP_SDO/AP_AD0); also elsewhere on the board
MOSI2: U4.14 (AP_SDA/AP_SDIO/AP_SDI); also elsewhere on the board
SCK2: U4.13 (AP_SCL/AP_SCLK); also elsewhere on the board
SCL1: R9.2, U5.8 (SCLK); also elsewhere on the board
SDA1: R8.2, U5.7 (SDI/SDA); also elsewhere on the board

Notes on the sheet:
Note: Using SPI Communication Protocol Software: Set to full accelerometer range, or implement variable ranges dependent on flight conditions
Note: Sensitive component, keep at "ambient" pressure
IMU - Gyro and Accelerometer +-16g
Barometer

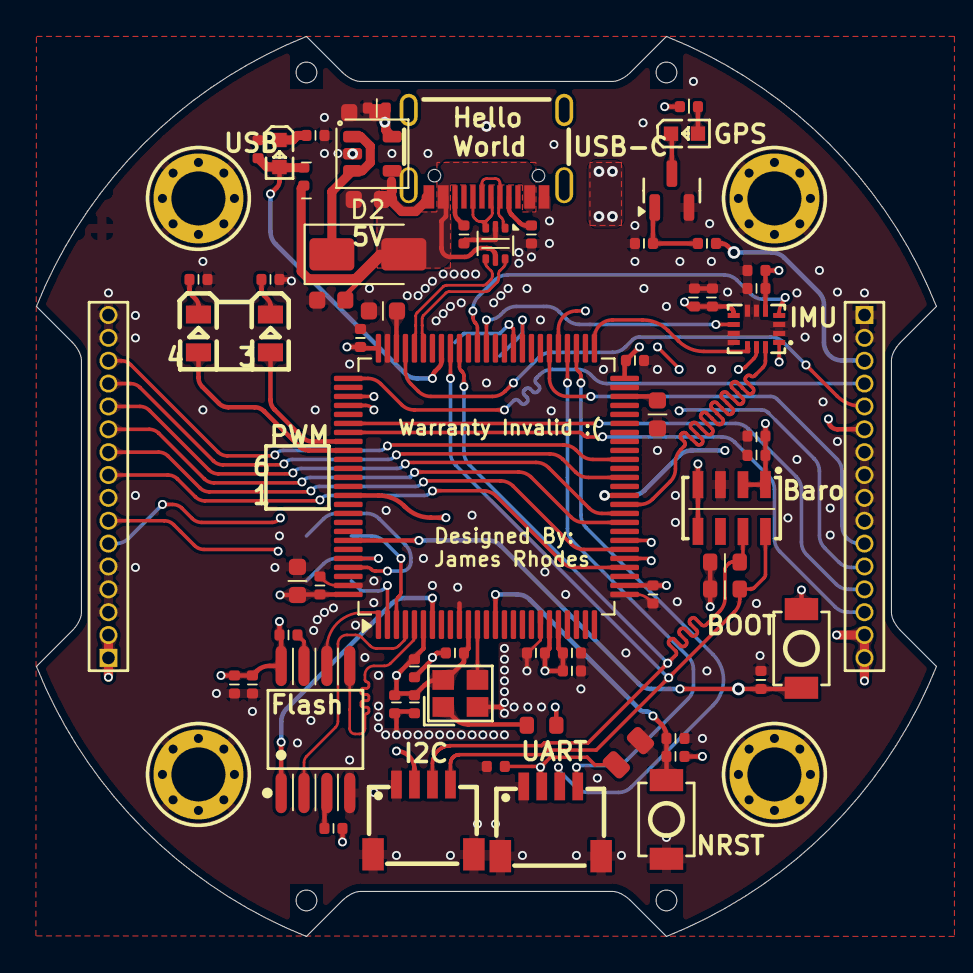
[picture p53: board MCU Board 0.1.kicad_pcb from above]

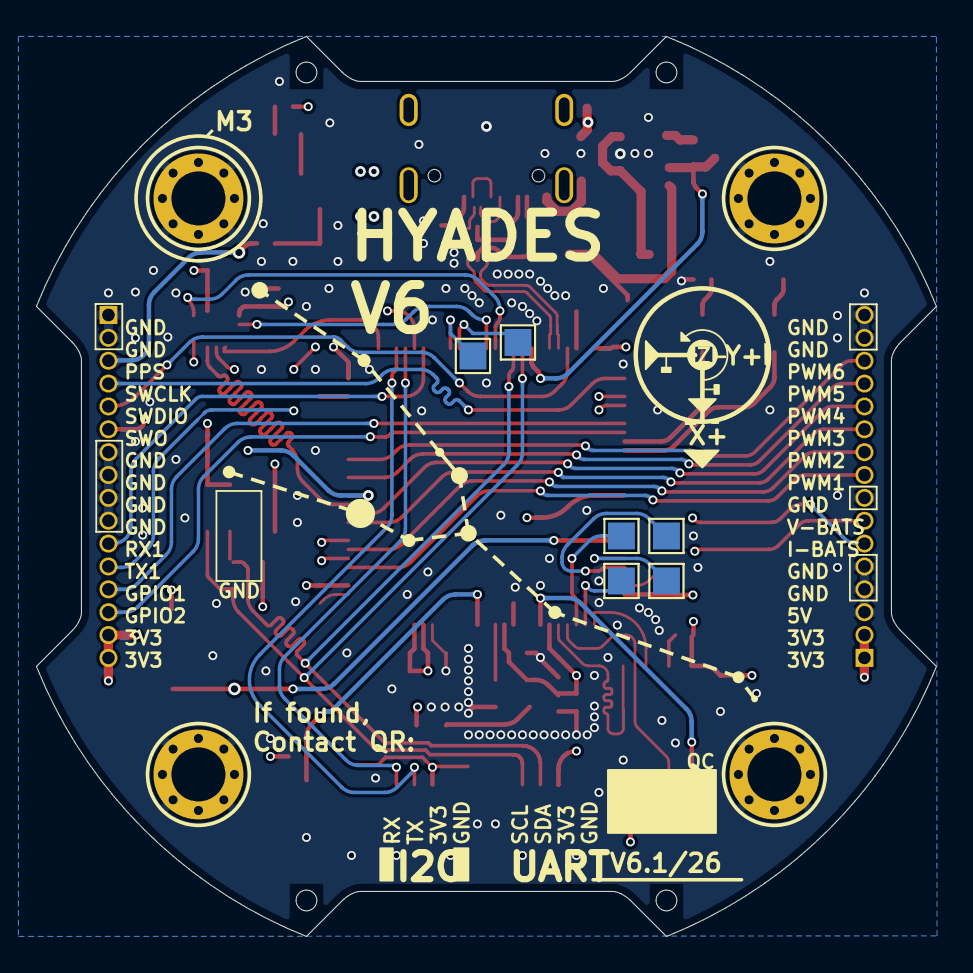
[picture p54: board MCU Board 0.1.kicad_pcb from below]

Board: 4 copper layers, 50.0 x 50.0 mm, 80 parts (6 on the bottom side), 63 nets.

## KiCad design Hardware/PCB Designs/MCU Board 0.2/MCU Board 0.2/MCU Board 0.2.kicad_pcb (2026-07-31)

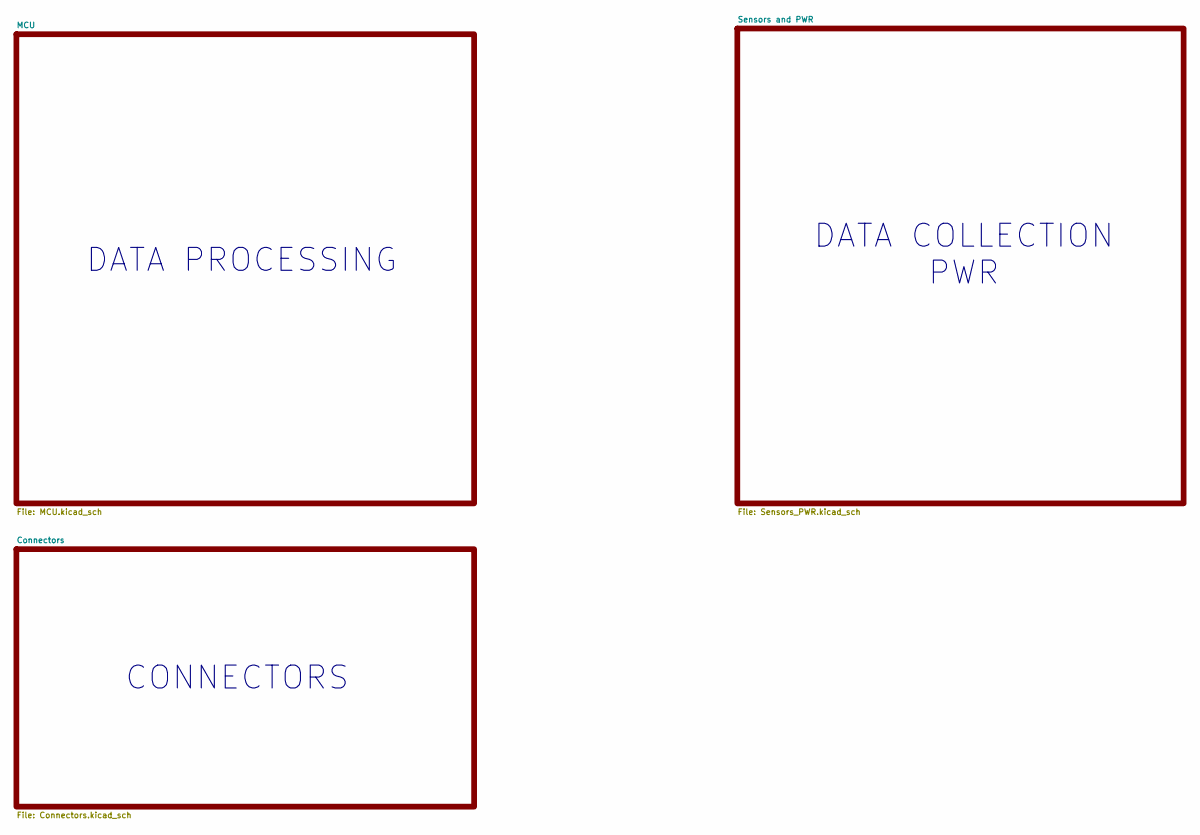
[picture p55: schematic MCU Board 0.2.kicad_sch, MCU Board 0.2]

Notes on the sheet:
CONNECTORS
DATA COLLECTION PWR
DATA PROCESSING

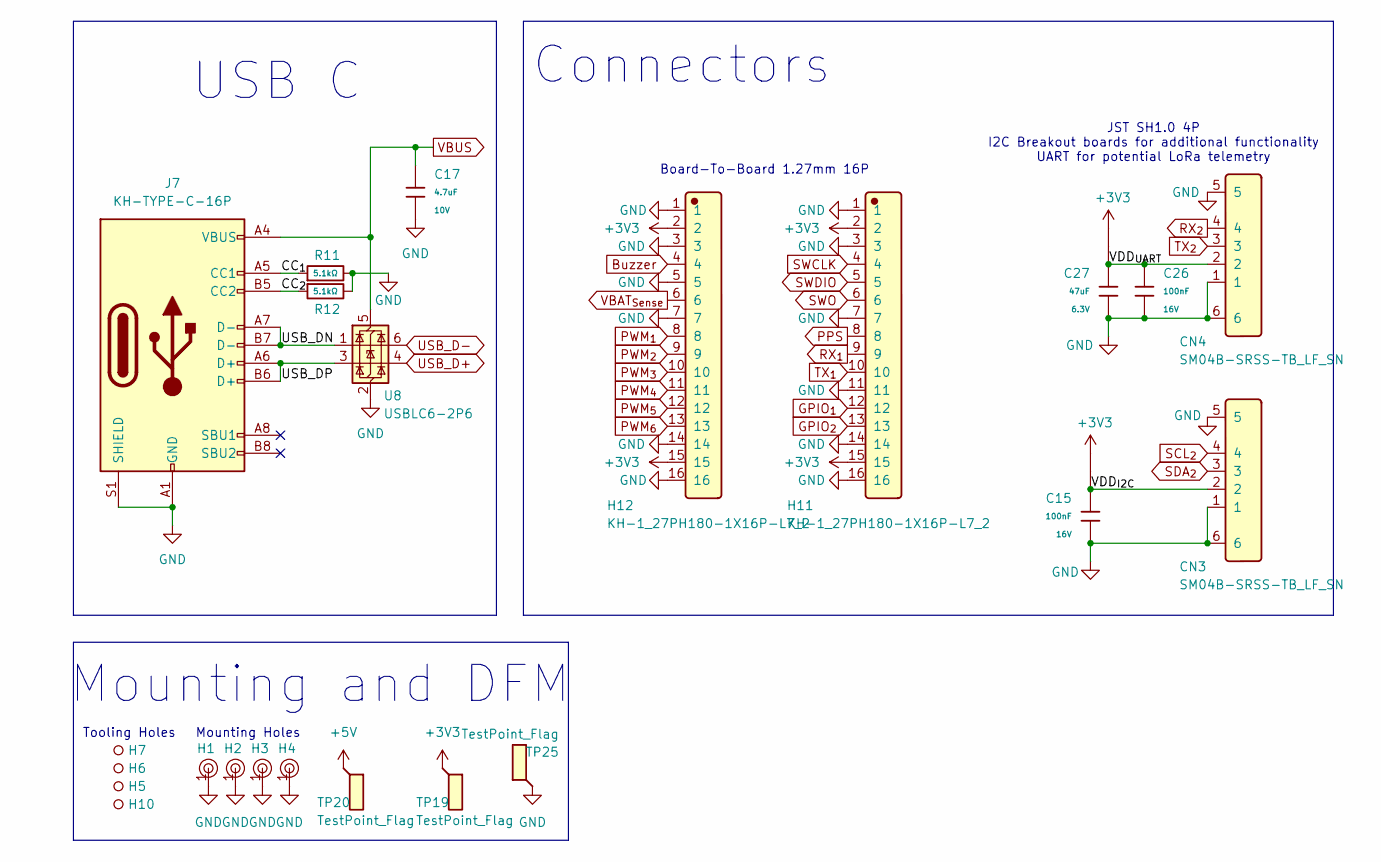
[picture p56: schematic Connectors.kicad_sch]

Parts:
C15, C26: 100nF; C_0402; Voltage Rated 16V; Tolerance ±10%; Part CL05B104KO5NNNC; LCSC C1525
C17: 4.7uF; C_0402; Voltage Rated 10V; Tolerance ±20%; Part CL05A475MP5NRNC; LCSC C23733
C27: 47uF; C_0805; Voltage Rated 6.3V; Tolerance ±20%; Part CL21A476MQYNNNE; LCSC C16780
CN3, CN4: SM04B-SRSS-TB_LF_SN; JST_SH_SM04B-SRSS-TB_1x04-1MP_P1.00mm_Horizontal; Manufacturer Part SM04B-SRSS-TB(LF)(SN); LCSC C160404
H1, H2, H3, H4: Hole, 3mm
H5, H6, H7, H10: Hole_Tooling_JLCPCB
H11, H12: KH-1_27PH180-1X16P-L7_2; Manufacturer Part KH-1.27PH180-1X16P-L7.2; LCSC C2938407
J7: KH-TYPE-C-16P; USB_C_Receptacle_GCT_USB4105-xx-A_16P_TopMnt_Horizontal
R11, R12: 5.1kΩ; R_0402; Overload Voltage (Max) 50V; Tolerance ±1%; Part 0402WGF5101TCE; LCSC C25905
TIE10, TIE11: NetTie; JUMPER_SMD_1x2_tiny_shorted; Part Number Do Not Place
TP19, TP20, TP25: TestPoint_Flag; SolderWirePad_1x01_SMD_2x4mm
U8: USBLC6-2P6; SOT-666

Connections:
+3V3: H11.2, H11.15, H12.2, H12.15, TIE10.2, TIE11.2, TP19.1 (1_1); also elsewhere on the board
+5V: TP20.1 (1_1); also elsewhere on the board
/Connectors/CC_{1}: J7.A5 (CC1), R11.1
/Connectors/CC_{2}: J7.B5 (CC2), R12.1
/Connectors/USB_DN: J7.A7 (D-), J7.B7 (D-), U8.1 (I/O1)
/Connectors/USB_DP: J7.A6 (D+), J7.B6 (D+), U8.3 (I/O2)
/Connectors/VDD_{I2C}: C15.1, CN3.2, TIE11.1
/Connectors/VDD_{UART}: C26.1, C27.1, CN4.2, TIE10.1
Buzzer: H12.4; also elsewhere on the board
GND: C15.2, C17.2, C26.2, C27.2, CN3.1, CN3.5, CN3.6, CN4.1, CN4.5, CN4.6, H1.1, H2.1, H3.1, H4.1, H11.1, H11.3, H11.7, H11.11, H11.14, H11.16, H12.1, H12.3, H12.5, H12.7, H12.14, H12.16, J7.A1 (GND), J7.A12 (GND), J7.B1 (GND), J7.B12 (GND), J7.S1 (SHIELD), R11.2, R12.2, TP25.1 (1_1), U8.2 (GND); also elsewhere on the board
GPIO_{1}: H11.12; also elsewhere on the board
GPIO_{2}: H11.13; also elsewhere on the board
PPS: H11.8; also elsewhere on the board
PWM_{1}: H12.8; also elsewhere on the board
PWM_{2}: H12.9; also elsewhere on the board
PWM_{3}: H12.10; also elsewhere on the board
PWM_{4}: H12.11; also elsewhere on the board
PWM_{5}: H12.12; also elsewhere on the board
PWM_{6}: H12.13; also elsewhere on the board
RX_{1}: H11.9; also elsewhere on the board
RX_{2}: CN4.4; also elsewhere on the board
SCL_{2}: CN3.4; also elsewhere on the board
SDA_{2}: CN3.3; also elsewhere on the board
SWCLK: H11.4; also elsewhere on the board
SWDIO: H11.5; also elsewhere on the board
SWO: H11.6; also elsewhere on the board
TX_{1}: H11.10; also elsewhere on the board
TX_{2}: CN4.3; also elsewhere on the board
USB_D+: U8.4 (I/O2); also elsewhere on the board
USB_D-: U8.6 (I/O1); also elsewhere on the board
VBAT_{Sense}: H12.6; also elsewhere on the board
VBUS: C17.1, J7.A4 (VBUS), J7.A9 (VBUS), J7.B4 (VBUS), J7.B9 (VBUS), U8.5 (VBUS); also elsewhere on the board

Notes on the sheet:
Tooling Holes
JST SH1.0 4P I2C Breakout boards for additional functionality UART for potential LoRa telemetry
USB C
Connectors
Board-To-Board 1.27mm 16P
Mounting and DFM
Mounting Holes

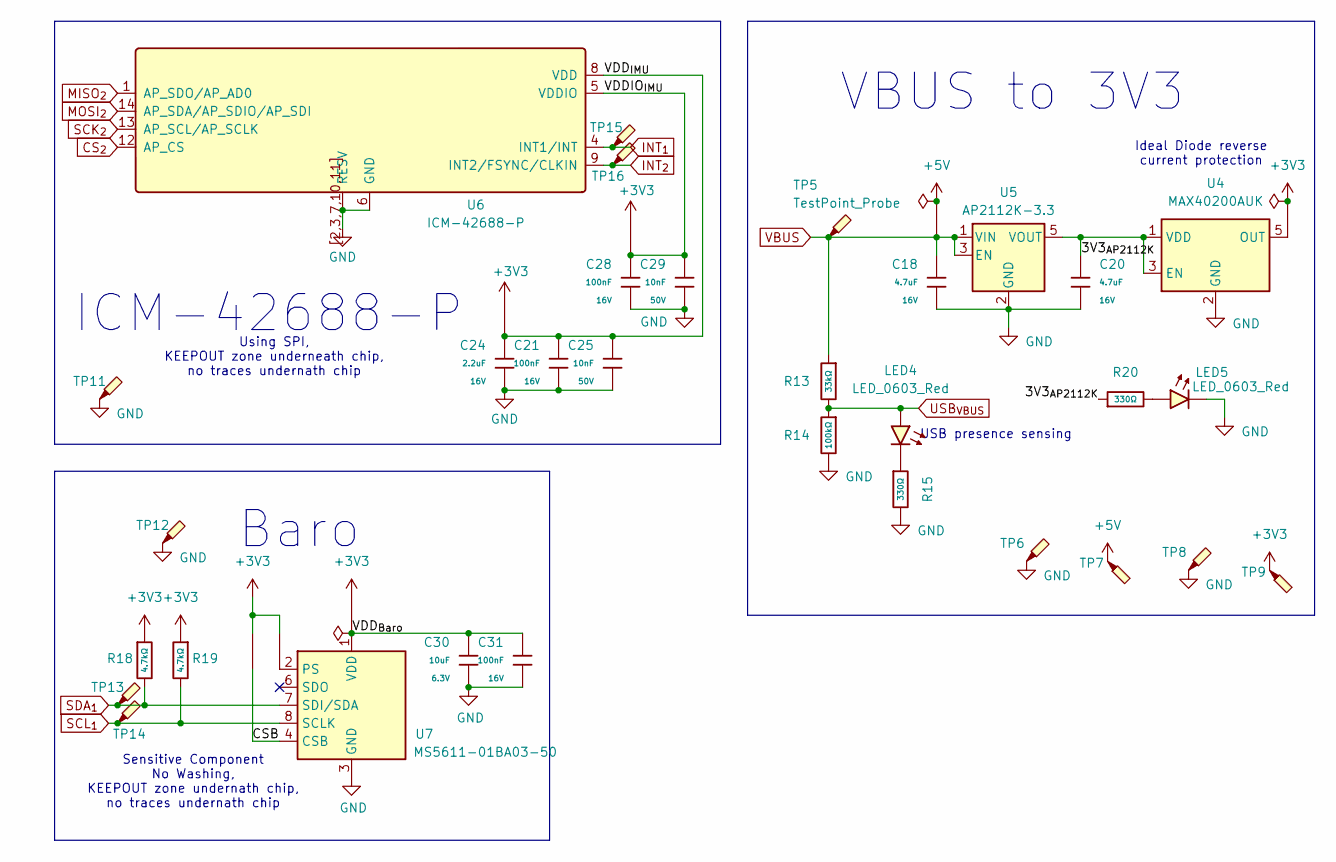
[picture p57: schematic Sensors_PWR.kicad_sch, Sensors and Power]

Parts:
C18, C20: 4.7uF; C_0603; Voltage Rated 16V; Tolerance ±10%; Part CL10A475KO8NNNC; LCSC C19666
C21, C28, C31: 100nF; C_0402; Voltage Rated 16V; Tolerance ±10%; Part CL05B104KO5NNNC; LCSC C1525
C24: 2.2uF; C_0603; Voltage Rated 16V; Tolerance ±10%; Part CL10A225KO8NNNC; LCSC C23630
C25, C29: 10nF; C_0402; Voltage Rated 50V; Tolerance ±10%; Part CL05B103KB5NNNC; LCSC C15195
C30: 10uF; C_0402; Voltage Rated 6.3V; Tolerance ±20%; Part CL05A106MQ5NUNC; LCSC C15525
LED4, LED5: LED_0603_Red; LED_0603_1608Metric
R13: 33kΩ; R_0402; Overload Voltage (Max) 50V; Tolerance ±1%; Part 0402WGF3302TCE; LCSC C25779
R14: 100kΩ; R_0402; Overload Voltage (Max) 50V; Tolerance ±1%; Part 0402WGF1003TCE; LCSC C25741
R15, R20: 330Ω; R_0402; Overload Voltage (Max) 50V; Tolerance ±1%; Part 0402WGF3300TCE; LCSC C25104
R18, R19: 4.7kΩ; R_0402; Overload Voltage (Max) 50V; Tolerance ±1%; Part 0402WGF4701TCE; LCSC C25900
TIE6, TIE7, TIE8, TIE9, TIE12, TIE13, TIE14: NetTie; JUMPER_SMD_1x2_tiny_shorted; Part Number Do Not Place
TP5, TP6, TP7, TP8, TP9, TP11, TP12, TP13, TP14, TP15, TP16: TestPoint_Probe; TestPoint_Pad_04
U4: MAX40200AUK; SOT-23-5
U5: AP2112K-3.3; SOT-23-5
U6: ICM-42688-P; Manufacturer Part ICM-42688-P; LCSC C1850418
U7: MS5611-01BA03-50; LGA-8_3x5mm_P1.25mm

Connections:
+3V3: R18.1, R19.1, TIE6.2, TIE7.2, TIE9.2, TIE12.2, TIE13.2, TIE14.2, TP9.1 (1_1); also elsewhere on the board
+5V: TIE8.2, TP7.1 (1_1); also elsewhere on the board
/Sensors and PWR/3V3_{AP2112K}: C20.1, R20.1, U4.1 (VDD), U4.3 (EN), U5.5 (VOUT)
/Sensors and PWR/CSB: TIE14.1, U7.4 (CSB), U7.5 (CSB)
/Sensors and PWR/VDDIO_{IMU}: C28.1, C29.1, TIE6.1, U6.5 (VDDIO)
/Sensors and PWR/VDD_{Baro}: C30.1, C31.1, TIE12.1, U7.1 (VDD)
/Sensors and PWR/VDD_{IMU}: C21.1, C24.1, C25.1, TIE7.1, U6.8 (VDD)
CS_{2}: U6.12 (AP_CS); also elsewhere on the board
GND: C18.2, C20.2, C21.2, C24.2, C25.2, C28.2, C29.2, C30.2, C31.2, LED5.1 (K), R14.2, R15.2, TP6.1 (1_1), TP8.1 (1_1), TP11.1 (1_1), TP12.1 (1_1), U4.2 (GND), U5.2 (GND), U6.2 (RESV), U6.3 (RESV), U6.6 (GND), U6.7 (RESV), U6.10 (RESV), U6.11 (RESV), U6.[2,3,7,10,11] (RESV), U7.3 (GND); also elsewhere on the board
INT_{1}: TP15.1 (1_1), U6.4 (INT1/INT); also elsewhere on the board
INT_{2}: TP16.1 (1_1), U6.9 (INT2/FSYNC/CLKIN); also elsewhere on the board
MISO_{2}: U6.1 (AP_SDO/AP_AD0); also elsewhere on the board
MOSI_{2}: U6.14 (AP_SDA/AP_SDIO/AP_SDI); also elsewhere on the board
unnamed: LED4.1 (K), R15.1
unnamed: LED5.2 (A), R20.2
unnamed: TIE9.1, U4.5 (OUT)
unnamed: TIE13.1, U7.2 (PS)
SCK_{2}: U6.13 (AP_SCL/AP_SCLK); also elsewhere on the board
SCL_{1}: R19.2, TP14.1 (1_1), U7.8 (SCLK); also elsewhere on the board
SDA_{1}: R18.2, TP13.1 (1_1), U7.7 (SDI/SDA); also elsewhere on the board
USB_{VBUS}: LED4.2 (A), R13.2, R14.1; also elsewhere on the board
VBUS: C18.1, R13.1, TIE8.1, TP5.1 (1_1), U5.1 (VIN), U5.3 (EN); also elsewhere on the board

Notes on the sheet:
Baro
VBUS to 3V3
ICM-42688-P
Sensitive Component No Washing, KEEPOUT zone undernath chip, no traces undernath chip
Ideal Diode reverse current protection
USB presence sensing
Using SPI, KEEPOUT zone underneath chip, no traces undernath chip

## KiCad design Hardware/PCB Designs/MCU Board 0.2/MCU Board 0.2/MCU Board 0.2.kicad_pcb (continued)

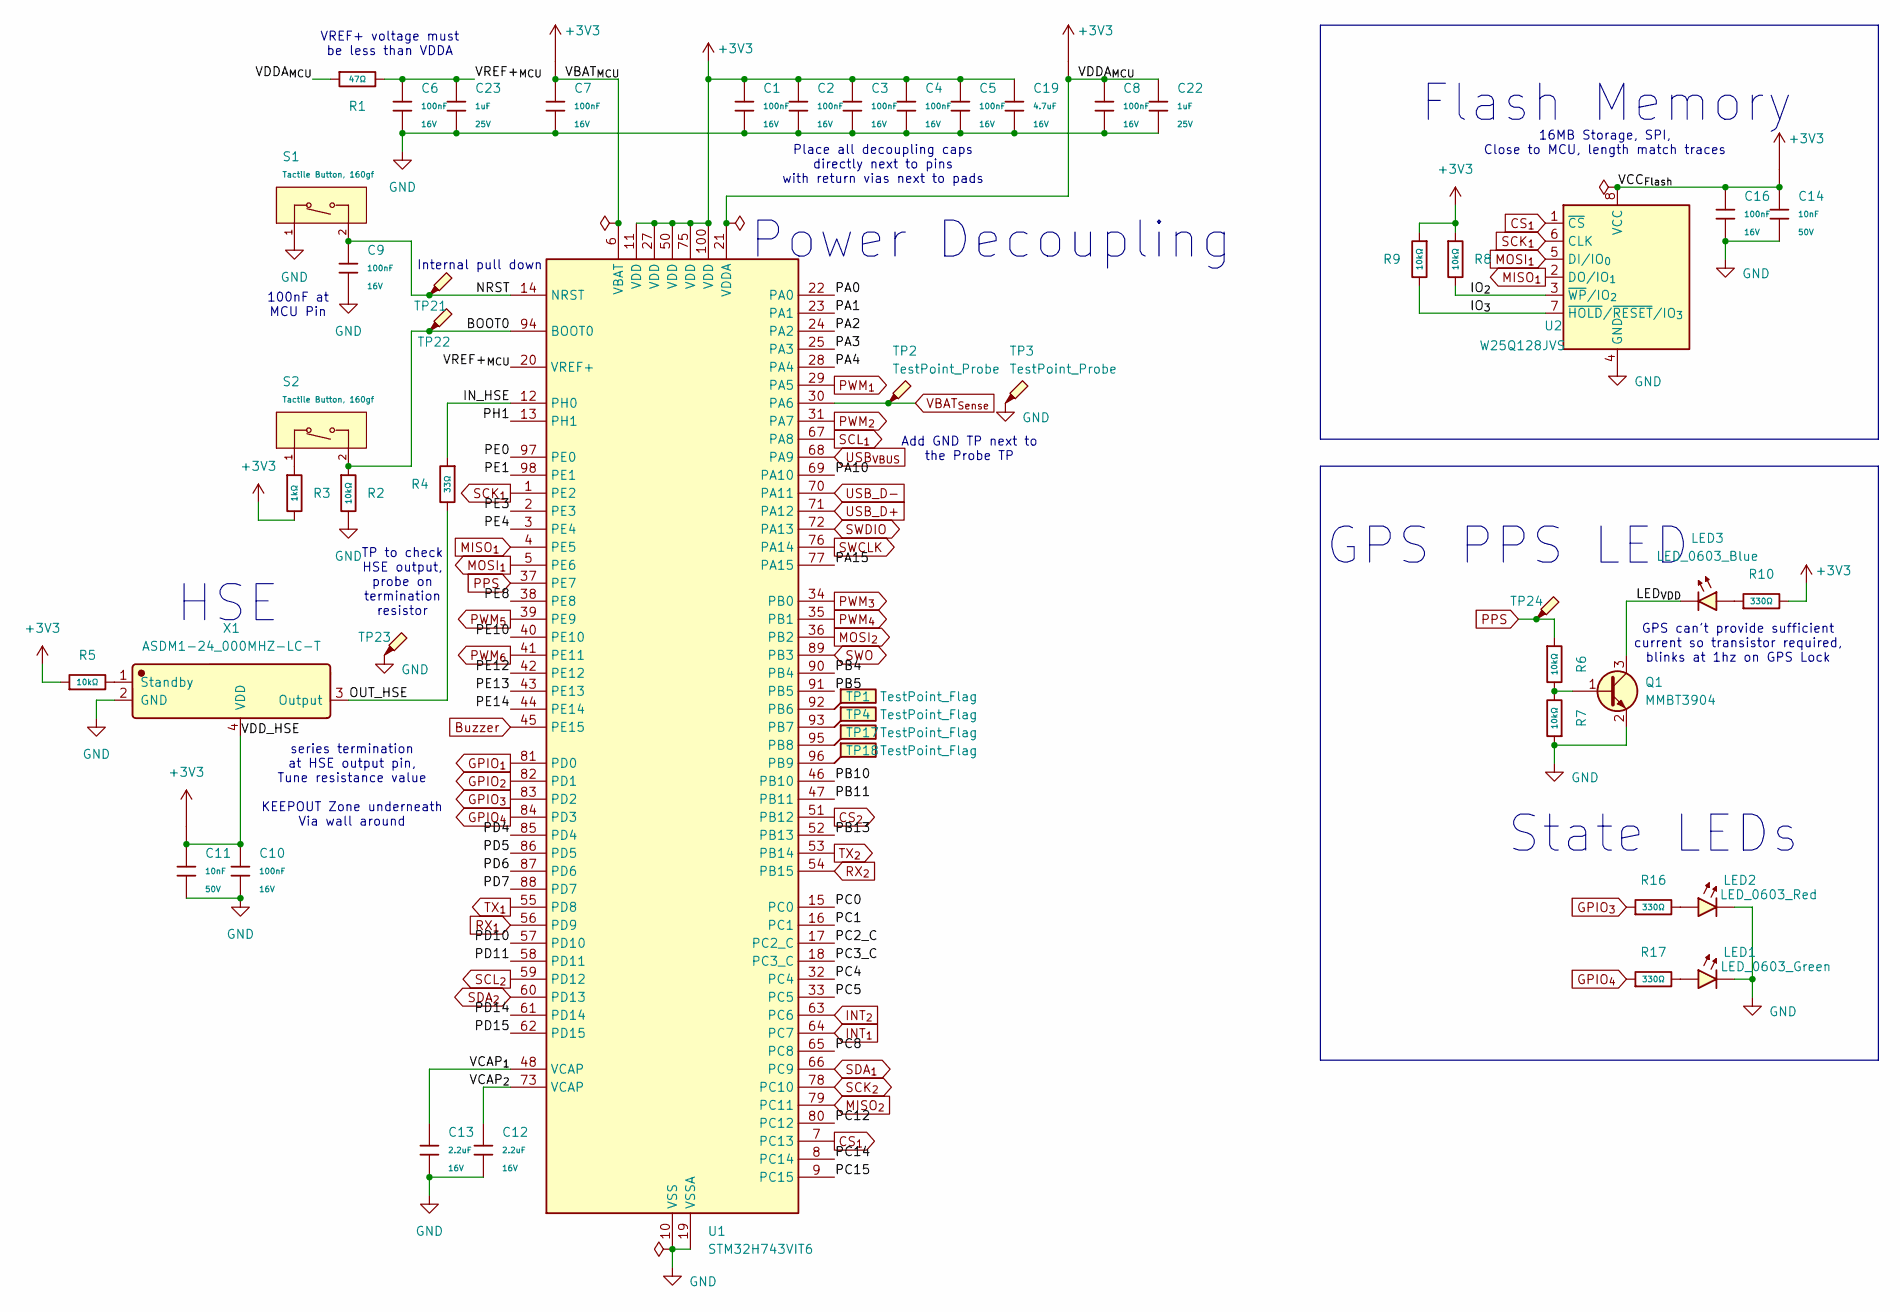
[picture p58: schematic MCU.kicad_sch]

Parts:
C1, C2, C3, C4, C5, C6, C7, C8, C9, C10, C16: 100nF; C_0402; Voltage Rated 16V; Tolerance ±10%; Part CL05B104KO5NNNC; LCSC C1525
C11, C14: 10nF; C_0402; Voltage Rated 50V; Tolerance ±10%; Part CL05B103KB5NNNC; LCSC C15195
C12, C13: 2.2uF; C_0603; Voltage Rated 16V; Tolerance ±10%; Part CL10A225KO8NNNC; LCSC C23630
C19: 4.7uF; C_0603; Voltage Rated 16V; Tolerance ±10%; Part CL10A475KO8NNNC; LCSC C19666
C22, C23: 1uF; C_0402; Voltage Rated 25V; Tolerance ±10%; Part CL05A105KA5NQNC; LCSC C52923
LED1: LED_0603_Green; LED_0603_1608Metric
LED2: LED_0603_Red; LED_0603_1608Metric
LED3: LED_0603_Blue; LED_0603_1608Metric
Q1: MMBT3904; SOT-23
R1: 47Ω; R_0402; Overload Voltage (Max) 50V; Tolerance ±1%; Part 0402WGF470JTCE; LCSC C25118
R2, R5, R6, R7, R8, R9: 10kΩ; R_0402; Overload Voltage (Max) 50V; Tolerance ±1%; Part 0402WGF1002TCE; LCSC C25744
R3: 1kΩ; R_0402; Overload Voltage (Max) 50V; Tolerance ±1%; Part 0402WGF1001TCE; LCSC C11702
R4: 33Ω; R_0402; Overload Voltage (Max) 50V; Tolerance ±1%; Part 0402WGF330JTCE; LCSC C25105
R10, R16, R17: 330Ω; R_0402; Overload Voltage (Max) 50V; Tolerance ±1%; Part 0402WGF3300TCE; LCSC C25104
S1, S2: Tactile Button, 160gf; SW_TS-1088-AR02016; Voltage Rating (Dc) 12V; Part TS-1088-AR02016; LCSC C720477
TIE1, TIE3, TIE4, TIE5: NetTie; JUMPER_SMD_1x2_tiny_shorted; Part Number Do Not Place
TP1, TP4, TP17, TP18: TestPoint_Flag; TestPoint_Pad_04
TP2, TP3, TP21, TP22, TP23, TP24: TestPoint_Probe; TestPoint_Pad_04
U1: STM32H743VIT6; LQFP-100_14x14mm_P0.5mm
U2: W25Q128JVS; SOIC-8_5.3x5.3mm_P1.27mm
X1: ASDM1-24_000MHZ-LC-T; OSC-SMD_4P-L3.2-W2.5-BL; Manufacturer Part ASDM1-24.000MHZ-LC-T; LCSC C1987235

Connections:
+3V3: C1.1, C2.1, C3.1, C4.1, C5.1, C19.1, R3.2, R5.1, R8.1, R9.1, R10.2, TIE1.2, TIE3.2, TIE4.2, TIE5.2, U1.11 (VDD), U1.27 (VDD), U1.50 (VDD), U1.75 (VDD), U1.100 (VDD); also elsewhere on the board
/MCU/BOOT0: R2.1, S2.2 (B), TP22.1 (1_1), U1.94 (BOOT0)
/MCU/IN_HSE: R4.1, U1.12 (PH0)
/MCU/IO_{2}: R8.2, U2.3 (~WP/IO_{2})
/MCU/IO_{3}: R9.2, U2.7 (~HOLD/~RESET/IO_{3})
/MCU/LED_{VDD}: LED3.1 (K), Q1.3 (C)
/MCU/NRST: C9.1, S1.2 (B), TP21.1 (1_1), U1.14 (NRST)
/MCU/OUT_HSE: R4.2, X1.3 (Output)
/MCU/PA0: U1.22 (PA0)
/MCU/PA1: U1.23 (PA1)
/MCU/PA2: U1.24 (PA2)
/MCU/PA3: U1.25 (PA3)
/MCU/PA4: U1.28 (PA4)
/MCU/PA10: U1.69 (PA10)
/MCU/PA15: U1.77 (PA15)
/MCU/PB4: U1.90 (PB4)
/MCU/PB5: U1.91 (PB5)
/MCU/PB10: U1.46 (PB10)
/MCU/PB11: U1.47 (PB11)
/MCU/PB13: U1.52 (PB13)
/MCU/PC0: U1.15 (PC0)
/MCU/PC1: U1.16 (PC1)
/MCU/PC2_C: U1.17 (PC2_C)
/MCU/PC3_C: U1.18 (PC3_C)
/MCU/PC4: U1.32 (PC4)
/MCU/PC5: U1.33 (PC5)
/MCU/PC8: U1.65 (PC8)
/MCU/PC12: U1.80 (PC12)
/MCU/PC14: U1.8 (PC14)
/MCU/PC15: U1.9 (PC15)
/MCU/PD4: U1.85 (PD4)
/MCU/PD5: U1.86 (PD5)
/MCU/PD6: U1.87 (PD6)
/MCU/PD7: U1.88 (PD7)
/MCU/PD10: U1.57 (PD10)
/MCU/PD11: U1.58 (PD11)
/MCU/PD14: U1.61 (PD14)
/MCU/PD15: U1.62 (PD15)
/MCU/PE0: U1.97 (PE0)
/MCU/PE1: U1.98 (PE1)
/MCU/PE3: U1.2 (PE3)
/MCU/PE4: U1.3 (PE4)
/MCU/PE8: U1.38 (PE8)
/MCU/PE10: U1.40 (PE10)
/MCU/PE12: U1.42 (PE12)
/MCU/PE13: U1.43 (PE13)
/MCU/PE14: U1.44 (PE14)
/MCU/PH1: U1.13 (PH1)
/MCU/VBAT_{MCU}: C7.1, TIE1.1, U1.6 (VBAT)
/MCU/VCAP_{1}: C13.1, U1.48 (VCAP)
/MCU/VCAP_{2}: C12.1, U1.73 (VCAP)
/MCU/VCC_{Flash}: C14.1, C16.1, TIE5.1, U2.8 (VCC)
/MCU/VDDA_{MCU}: C8.1, C22.1, R1.1, TIE3.1, U1.21 (VDDA)
/MCU/VDD_HSE: C10.1, C11.1, TIE4.1, X1.4 (VDD)
/MCU/VREF+_{MCU}: C6.1, C23.1, R1.2, U1.20 (VREF+)
Buzzer: U1.45 (PE15); also elsewhere on the board
CS_{1}: U1.7 (PC13), U2.1 (~CS)
CS_{2}: U1.51 (PB12); also elsewhere on the board
GND: C1.2, C2.2, C3.2, C4.2, C5.2, C6.2, C7.2, C8.2, C9.2, C10.2, C11.2, C12.2, C13.2, C14.2, C16.2, C19.2, C22.2, C23.2, LED1.1 (K), LED2.1 (K), Q1.2 (E), R2.2, R7.1, S1.1 (A), TP3.1 (1_1), TP23.1 (1_1), U1.10 (VSS), U1.19 (VSSA), U1.26 (VSS), U1.49 (VSS), U1.74 (VSS), U1.99 (VSS), U2.4 (GND), X1.2 (GND); also elsewhere on the board
GPIO_{1}: U1.81 (PD0); also elsewhere on the board
GPIO_{2}: U1.82 (PD1); also elsewhere on the board
GPIO_{3}: R16.1, U1.83 (PD2)
GPIO_{4}: R17.1, U1.84 (PD3)
INT_{1}: U1.64 (PC7); also elsewhere on the board
INT_{2}: U1.63 (PC6); also elsewhere on the board
MISO_{1}: U1.4 (PE5), U2.2 (DO/IO_{1})
MISO_{2}: U1.79 (PC11); also elsewhere on the board
MOSI_{1}: U1.5 (PE6), U2.5 (DI/IO_{0})
MOSI_{2}: U1.36 (PB2); also elsewhere on the board
unnamed: LED1.2 (A), R17.2
unnamed: LED2.2 (A), R16.2
unnamed: LED3.2 (A), R10.1
unnamed: Q1.1 (B), R6.2, R7.2
unnamed: R3.1, S2.1 (A)
unnamed: TP1.1 (1_1), U1.92 (PB6)
unnamed: TP4.1 (1_1), U1.93 (PB7)
unnamed: TP17.1 (1_1), U1.95 (PB8)
unnamed: TP18.1 (1_1), U1.96 (PB9)
unnamed: R5.2, X1.1 (Standby)
PPS: R6.1, TP24.1 (1_1), U1.37 (PE7); also elsewhere on the board
PWM_{1}: U1.29 (PA5); also elsewhere on the board
PWM_{2}: U1.31 (PA7); also elsewhere on the board
PWM_{3}: U1.34 (PB0); also elsewhere on the board
PWM_{4}: U1.35 (PB1); also elsewhere on the board
PWM_{5}: U1.39 (PE9); also elsewhere on the board
PWM_{6}: U1.41 (PE11); also elsewhere on the board
RX_{1}: U1.56 (PD9); also elsewhere on the board
RX_{2}: U1.54 (PB15); also elsewhere on the board
SCK_{1}: U1.1 (PE2), U2.6 (CLK)
SCK_{2}: U1.78 (PC10); also elsewhere on the board
SCL_{1}: U1.67 (PA8); also elsewhere on the board
SCL_{2}: U1.59 (PD12); also elsewhere on the board
SDA_{1}: U1.66 (PC9); also elsewhere on the board
SDA_{2}: U1.60 (PD13); also elsewhere on the board
SWCLK: U1.76 (PA14); also elsewhere on the board
SWDIO: U1.72 (PA13); also elsewhere on the board
SWO: U1.89 (PB3); also elsewhere on the board
TX_{1}: U1.55 (PD8); also elsewhere on the board
TX_{2}: U1.53 (PB14); also elsewhere on the board
USB_D+: U1.71 (PA12); also elsewhere on the board
USB_D-: U1.70 (PA11); also elsewhere on the board
USB_{VBUS}: U1.68 (PA9); also elsewhere on the board
VBAT_{Sense}: TP2.1 (1_1), U1.30 (PA6); also elsewhere on the board

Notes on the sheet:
TP to check HSE output, probe on termination resistor
Add GND TP next to the Probe TP
100nF at MCU Pin
16MB Storage, SPI, Close to MCU, length match traces
GPS can't provide sufficient current so transistor required, blinks at 1hz on GPS Lock
VREF+ voltage must be less than VDDA
HSE
Flash Memory
GPS PPS LED
Internal pull down
Place all decoupling caps directly next to pins with return vias next to pads
State LEDs
series termination at HSE output pin, Tune resistance value KEEPOUT Zone underneath Via wall around
Power Decoupling

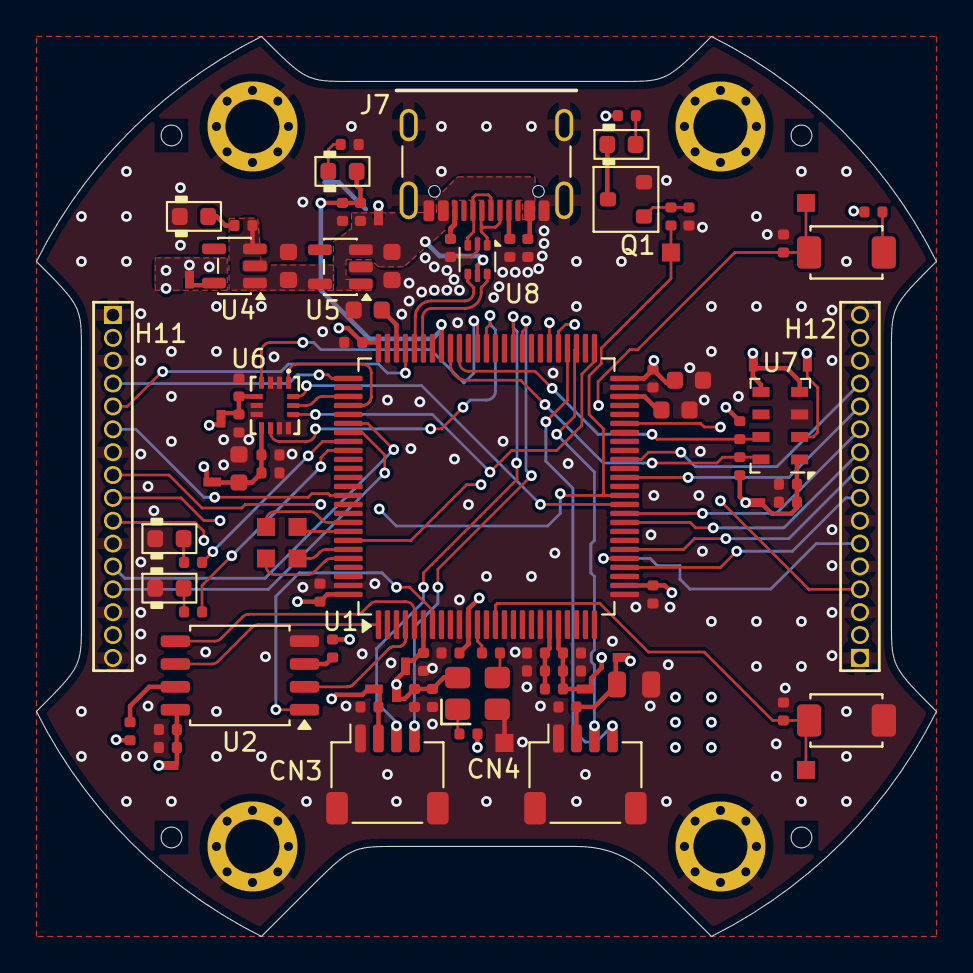
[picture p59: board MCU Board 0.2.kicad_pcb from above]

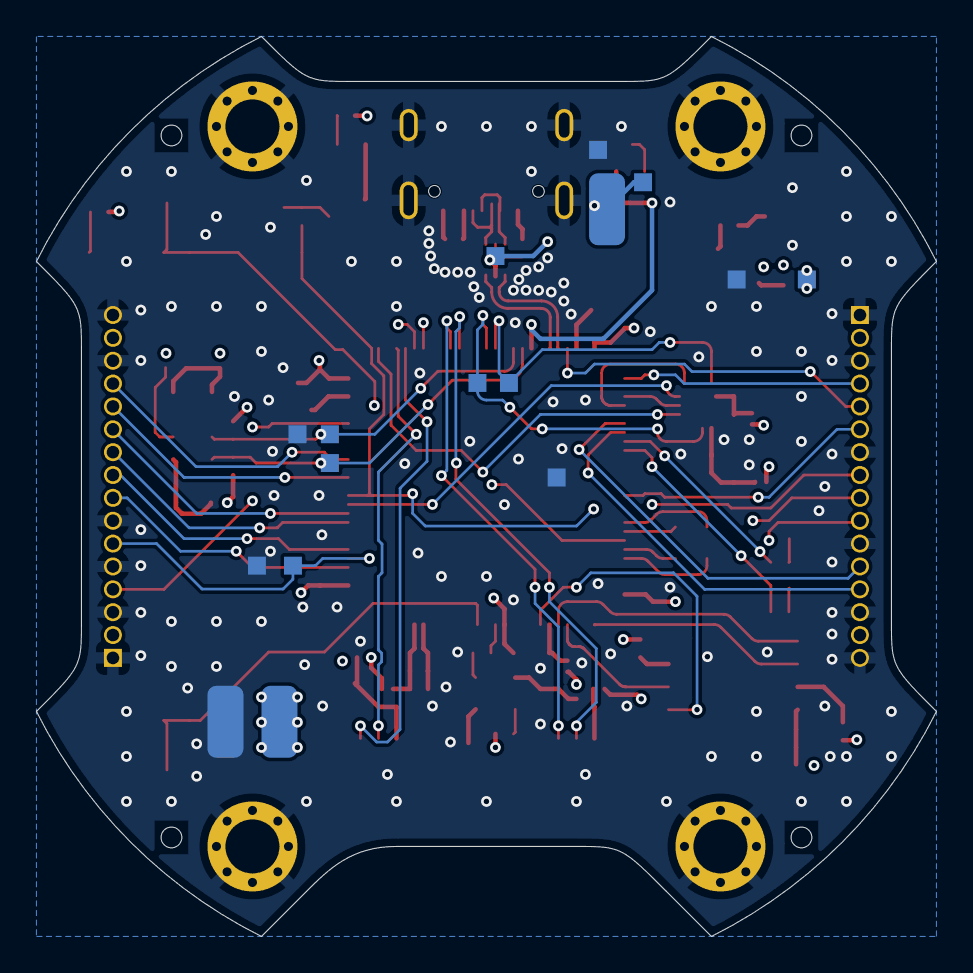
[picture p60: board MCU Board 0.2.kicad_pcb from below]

Board: 4 copper layers, 50.0 x 50.0 mm, 117 parts (16 on the bottom side), 80 nets.

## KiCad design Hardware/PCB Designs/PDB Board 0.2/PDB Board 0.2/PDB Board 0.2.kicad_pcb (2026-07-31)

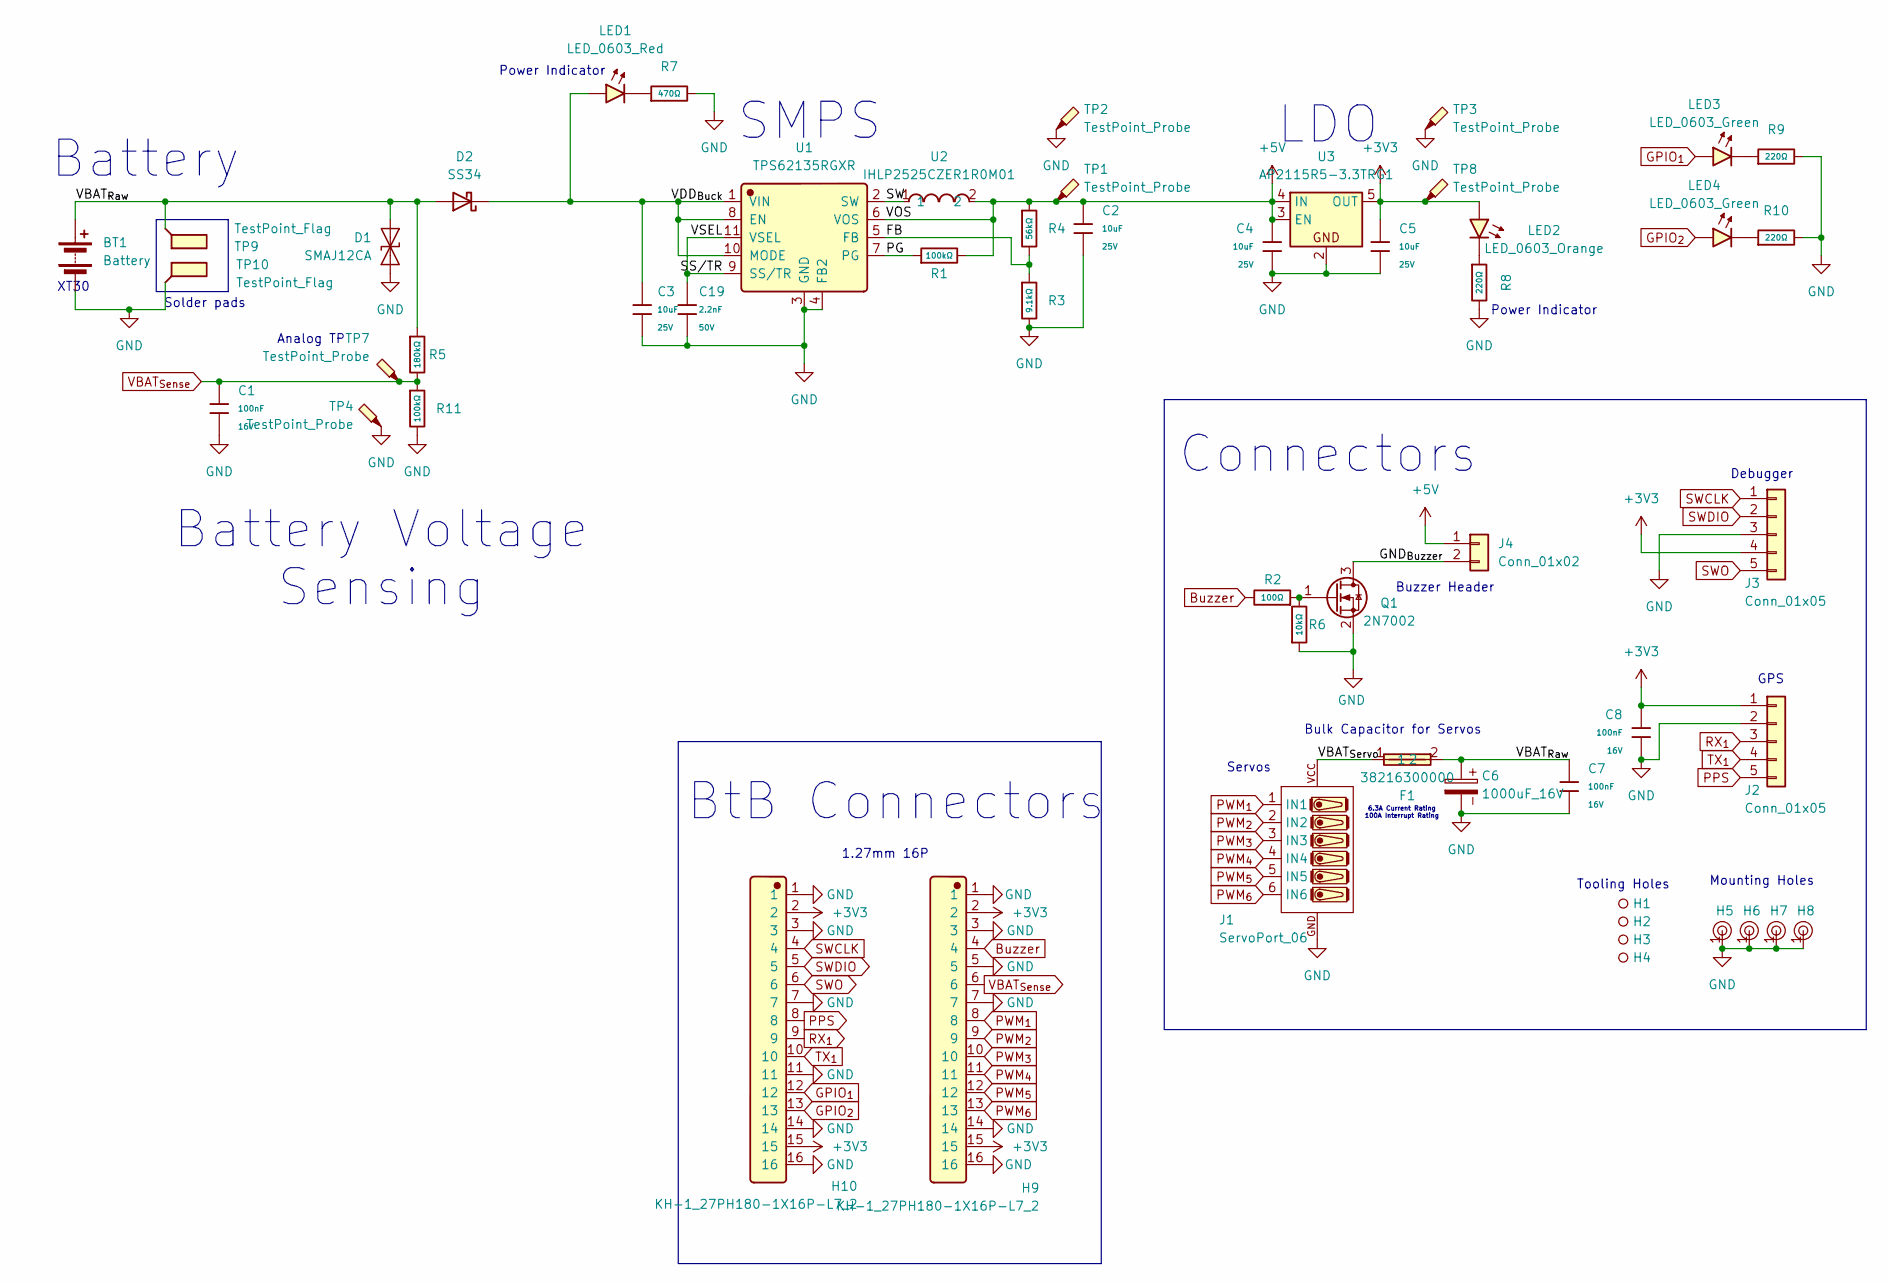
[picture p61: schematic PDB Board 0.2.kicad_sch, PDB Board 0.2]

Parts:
BT1: Battery; AMASS_XT30UPB-F_1x02_P5.0mm_Vertical
C1, C7, C8: 100nF; C_0402; Voltage Rated 16V; Tolerance ±10%; Part CL05B104KO5NNNC; LCSC C1525
C2, C3, C4, C5: 10uF; C_0805; Voltage Rated 25V; Tolerance ±10%; Part CL21A106KAYNNNE; LCSC C15850
C6: 1000uF_16V; CP_Radial_D10.0mm_P5.00mm
C19: 2.2nF; C_0402; Voltage Rated 50V; Tolerance ±10%; Part 0402B222K500NT; LCSC C1531
D1: SMAJ12CA; D_SMA
D2: SS34; D_SMA
F1: 38216300000; Manufacturer Part 38216300000; LCSC C142713
H1, H2, H3, H4: Hole_Tooling_JLCPCB
H5, H6, H7, H8: Hole, 3mm
H9, H10: KH-1_27PH180-1X16P-L7_2; Manufacturer Part KH-1.27PH180-1X16P-L7.2; LCSC C2938407
J1: ServoPort_06; ServoPort_06_Vertical
J2, J3: Conn_01x05; JST_XH_B5B-XH-A_1x05_P2.50mm_Vertical
J4: Conn_01x02; JST_XH_B2B-XH-A_1x02_P2.50mm_Vertical; Part Number 1-0201FBV0T
LED1: LED_0603_Red; LED_0603_1608Metric
LED2: LED_0603_Orange; LED_0603_1608Metric
LED3, LED4: LED_0603_Green; LED_0603_1608Metric
Q1: 2N7002; SOT-23
R1, R11: 100kΩ; R_0402; Overload Voltage (Max) 50V; Tolerance ±1%; Part 0402WGF1003TCE; LCSC C25741
R2: 100Ω; R_0402; Overload Voltage (Max) 50V; Tolerance ±1%; Part 0402WGF1000TCE; LCSC C25076
R3: 9.1kΩ; R_0603; Overload Voltage (Max) 75V; Tolerance ±1%; Part 0603WAF9101T5E; LCSC C23260
R4: 56kΩ; R_0603; Overload Voltage (Max) 75V; Tolerance ±1%; Part 0603WAF5602T5E; LCSC C23206
R5: 180kΩ; R_0603; Overload Voltage (Max) 75V; Tolerance ±1%; Part 0603WAF1803T5E; LCSC C22827
R6: 10kΩ; R_0402; Overload Voltage (Max) 50V; Tolerance ±1%; Part 0402WGF1002TCE; LCSC C25744
R7: 470Ω; R_0402; Overload Voltage (Max) 50V; Tolerance ±1%; Part 0402WGF4700TCE; LCSC C25117
R8, R9, R10: 220Ω; R_0402; Overload Voltage (Max) 50V; Tolerance ±1%; Part 0402WGF2200TCE; LCSC C25091
TP1, TP2, TP3, TP4, TP7, TP8: TestPoint_Probe; TestPoint_Pad_04
TP9, TP10: TestPoint_Flag; SolderWirePad_1x01_SMD_4x8mm
U1: TPS62135RGXR; Manufacturer Part TPS62135RGXR; LCSC C167238
U2: IHLP2525CZER1R0M01; Manufacturer Part IHLP2525CZER1R0M01; LCSC C845018
U3: AP2115R5-3.3TRG1; Diodes_SOT-89-5

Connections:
+3V3: C5.1, C8.1, H9.2, H9.15, H10.2, H10.15, J2.1, J3.4, LED2.2 (A), TP8.1 (1_1), U3.5 (OUT)
+5V: C2.1, C4.1, J4.1, R1.2, R4.1, TP1.1 (1_1), U1.6 (VOS), U2.2, U3.3 (EN), U3.4 (IN)
/FB: R3.1, R4.2, U1.5 (FB)
/GND_{Buzzer}: J4.2, Q1.3 (D)
/PG: R1.1, U1.7 (PG)
/SS/TR: C19.1, U1.9 (SS/TR), U1.11 (VSEL)
/SW: U1.2 (SW), U2.1
/VBAT_{Raw}: BT1.1 (+), C6.1, C7.1, D1.2 (A2), D2.2 (A), F1.2, R5.1, TP9.1 (1_1)
/VBAT_{Servo}: F1.1, J1.VCC
/VDD_{Buck}: C3.1, D2.1 (K), LED1.2 (A), U1.1 (VIN), U1.8 (EN), U1.10 (MODE)
Buzzer: H9.4, R2.2
GND: BT1.2 (-), C1.2, C2.2, C3.2, C4.2, C5.2, C6.2, C7.2, C8.2, C19.2, D1.1 (A1), H5.1, H6.1, H7.1, H8.1, H9.1, H9.3, H9.5, H9.7, H9.14, H9.16, H10.1, H10.3, H10.7, H10.11, H10.14, H10.16, J1.GND, J2.2, J3.3, Q1.2 (S), R3.2, R6.1, R7.2, R8.2, R9.2, R10.2, R11.2, TP2.1 (1_1), TP3.1 (1_1), TP4.1 (1_1), TP10.1 (1_1), U1.3 (GND), U1.4 (FB2), U3.2
GPIO_{1}: H10.12, LED3.2 (A)
GPIO_{2}: H10.13, LED4.2 (A)
unnamed: LED1.1 (K), R7.1
unnamed: LED2.1 (K), R8.1
unnamed: LED3.1 (K), R9.1
unnamed: LED4.1 (K), R10.1
unnamed: Q1.1 (G), R2.1, R6.2
PPS: H10.8, J2.5
PWM_{1}: H9.8, J1.1 (IN1)
PWM_{2}: H9.9, J1.2 (IN2)
PWM_{3}: H9.10, J1.3 (IN3)
PWM_{4}: H9.11, J1.4 (IN4)
PWM_{5}: H9.12, J1.5 (IN5)
PWM_{6}: H9.13, J1.6 (IN6)
RX_{1}: H10.9, J2.3
SWCLK: H10.4, J3.1
SWDIO: H10.5, J3.2
SWO: H10.6, J3.5
TX_{1}: H10.10, J2.4
VBAT_{Sense}: C1.1, H9.6, R5.2, R11.1, TP7.1 (1_1)

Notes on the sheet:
Solder pads
BtB Connectors
XT30
6.3A Current Rating 100A Interrupt Rating
Servos
SMPS
Power Indicator
Bulk Capacitor for Servos
Connectors
Analog TP
1.27mm 16P
Mounting Holes
LDO
Battery
Buzzer Header
Battery Voltage Sensing
GPS
Debugger
Tooling Holes

Board: 4 copper layers, 54 parts (2 on the bottom side), 32 nets, no tracks yet.

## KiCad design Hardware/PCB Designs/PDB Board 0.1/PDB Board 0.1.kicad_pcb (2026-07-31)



Board: 4 copper layers, 50.0 x 50.0 mm, 52 parts (5 on the bottom side), 30 nets.

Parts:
BT1: Battery; AMASS_XT30UPB-M_1x02_P5.0mm_Vertical
C1, C4, C5: 100nF; C_0603
C6, C7: 10uF; C_1206
C9: 1000uF_16V; CP_Radial_D5.0mm_P2.50mm
C10: 100uF; C_1206
C11, C12: 10uF; C_0805
C18: 10uF; C_0603
C19: 2.2nF; C_0402
D1: SMAJ15A_C908769
D2: SS34; D_SMA
H1, H2, H3, H4: Hole, 3mm
H5, H6, H7, H8: Hole_Tooling_JLCPCB
H9: HX_PZ2_54-3X6P_ZZ
J7: Conn_01x05; JST_XH_B5B-XH-A_1x05_P2.50mm_Vertical
J8: Conn_01x05; PinHeader_1x05_P2.54mm_Vertical
LED1: KT-0603R
LED2, LED4: 17-21SUYC_TR8
LED3: 0805G_Green
R1: 100kΩ; R_0603
R2: 33kΩ; R_0603
R3: 10m_1206_250mW; R_1206_3216Metric
R4: 180kΩ; R_0603
R5: 470Ω; R_0603
R6, R7, R8: 220Ω; R_0402
R15: 62kΩ; R_0603
R16: 10kΩ; R_0603
TP1: BATT-; TestPoint_Pad_4.0x4.0mm
TP2: BATT+; TestPoint_Pad_4.0x4.0mm
TP3, TP4, TP13, TP16, TP17: TestPoint; TestPoint_Pad_D1.0mm
U1: TPS62135RGXR
U2: IHLP2525CZER1R0M01
U3: INA181A1IDBVT; SOT-23-6
U4: AP2115R5A-3.3TRG1; Diodes_SOT-89-5
U6, U7: X1311FV-16-C43D24

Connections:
+3V3: C12.1, J7.1, J8.4, LED2.1 (+), TP4.1 (1_1), U4.5 (OUT), U6.1, U6.2, U7.15, U7.16
+5V: C5.1, C6.1, C7.1, C11.1, R1.2, R15.1, TP3.1 (1_1), U1.6 (VOS), U2.2, U3.6 (V+), U4.1 (EN), U4.4 (IN), U6.3, U6.4
+BATT: BT1.1 (+), C1.1, C4.1, C9.1, C10.1, D2.2, H9.7, H9.8, H9.9, H9.10, H9.11, H9.12, TP2.1 (1_1)
/VDD_BUCK: C18.1, R3.2, U1.1 (VIN), U1.8 (EN), U3.3 (+)
GND: BT1.2 (-), C1.2, C4.2, C5.2, C6.2, C7.2, C9.2, C10.2, C11.2, C12.2, C18.2, C19.2, D1.2, H1.1, H2.1, H3.1, H4.1, H9.1, H9.2, H9.3, H9.4, H9.5, H9.6, J7.2, J8.3, R2.2, R5.1, R6.2, R7.2, R8.2, R16.2, TP1.1 (1_1), U1.3 (GND), U1.4 (FB2), U1.10 (MODE), U1.11 (VSEL), U3.2 (GND), U3.5 (REF), U4.2, U6.5, U6.8, U6.15, U6.16, U7.1, U7.2, U7.7, U7.8, U7.9, U7.10
ISHUNT_DELTA: U3.1 (OUT), U6.6
unnamed: LED1.1 (K), R5.2
unnamed: LED2.2 (-), R6.1
unnamed: LED3.1 (A), TP16.1 (1_1), U7.13
unnamed: LED3.2 (K), R7.1
unnamed: LED4.1 (+), TP17.1 (1_1), U7.14
unnamed: LED4.2 (-), R8.1
unnamed: R15.2, R16.1, U1.5 (FB)
unnamed: R1.1, U1.7 (PG)
unnamed: C19.1, U1.9 (SS/TR)
unnamed: U1.2 (SW), U2.1
PPS: J7.5, U7.3
PWM1: H9.18, U6.9
PWM2: H9.17, U6.10
PWM3: H9.16, U6.11
PWM4: H9.15, U6.12
PWM5: H9.14, U6.13
PWM6: H9.13, U6.14
RX1: J7.3, U7.11
SWCLK: J8.1, U7.4
SWD: J8.5, U7.6
SWDIO: J8.2, U7.5
TX1: J7.4, U7.12
VBAT_SENSE: R2.1, R4.2, TP13.1 (1_1), U6.7
VDD: D1.1, D2.1, LED1.2 (A), R3.1, R4.1, U3.4 (-)

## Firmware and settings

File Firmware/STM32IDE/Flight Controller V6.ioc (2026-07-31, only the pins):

Mcu.UserName=STM32H743VITx
PA11.GPIO_Label=USB_D-
PA11.Signal=USB_OTG_FS_DM
PA12.GPIO_Label=USB_D+
PA12.Signal=USB_OTG_FS_DP
PA5.GPIO_Label=PWM1
PA5.Signal=TIM8_CH1N
PA6.GPIO_Label=VBAT_SENSE
PA6.Signal=ADCx_INP3
PA7.GPIO_Label=PWM2
PA7.Signal=TIM1_CH1N
PA8.GPIO_Label=SCL1
PA8.Signal=I2C3_SCL
PA9.GPIO_Label=USB_VBUS
PA9.Signal=USB_OTG_FS_VBUS
PB0.GPIO_Label=PWM3
PB0.Signal=TIM1_CH2N
PB1.GPIO_Label=PWM4
PB1.Signal=TIM1_CH3N
PB12.GPIO_Label=CS2
PB12.Signal=GPIO_Output
PB14.GPIO_Label=TX2
PB14.Signal=USART1_TX
PB15.GPIO_Label=RX2
PB15.Signal=USART1_RX
PB2.GPIO_Label=SPI_MOSI2
PB2.Signal=SPI3_MOSI
PB5.GPIO_Label=ISHUNT_DELTA
PB5.Signal=GPIO_Analog
PB6.GPIO_Label=VBAT_SENSE
PB6.Signal=GPIO_Analog
PC10.GPIO_Label=SPI_SCK2
PC10.Signal=SPI3_SCK
PC11.GPIO_Label=SPI_MISO2
PC11.Signal=SPI3_MISO
PC13.GPIO_Label=CS1
PC13.Signal=GPIO_Output
PC4.GPIO_Label=ISHUNT_DELTA
PC4.Signal=ADCx_INP4
PC6.GPIO_Label=INT2
PC6.Signal=GPIO_Input
PC7.GPIO_Label=INT1
PC7.Signal=GPIO_Input
PC9.GPIO_Label=SDA1
PC9.Signal=I2C3_SDA
PD0.GPIO_Label=GPIO1
PD0.Signal=GPIO_Output
PD1.GPIO_Label=GPIO2
PD1.Signal=GPIO_Output
PD12.GPIO_Label=SCL2
PD12.Signal=I2C4_SCL
PD13.GPIO_Label=SDA2
PD13.Signal=I2C4_SDA
PD2.GPIO_Label=GPIO3
PD2.Signal=GPIO_Output
PD3.GPIO_Label=GPIO4
PD3.Signal=GPIO_Output
PD8.GPIO_Label=TX1
PD8.Signal=USART3_TX
PD9.GPIO_Label=RX1
PD9.Signal=USART3_RX
PE11.GPIO_Label=PWM6
PE11.Signal=S_TIM1_CH2
PE15.GPIO_Label=Buzzer
PE15.Signal=GPIO_Output
PE2.GPIO_Label=SPI_SCK1
PE2.Signal=SPI4_SCK
PE5.GPIO_Label=SPI_MISO1
PE5.Signal=SPI4_MISO
PE6.GPIO_Label=SPI_MOSI1
PE6.Signal=SPI4_MOSI
PE9.GPIO_Label=PWM5
PE9.Signal=S_TIM1_CH1

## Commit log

2026-07-04 Uploaded KiCad10 Parser Software
2026-07-05 Updated Kicad10 parser
2026-07-31 Add flight computer files
    [Buck Regulator SPICE Simulation.kicad_pcb, Buck Regulator SPICE Simulation.kicad_sch, Clock Test 0.1.kicad_pcb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]
2026-07-31 Add additional heatmap figures to README
2026-07-31 Clean up Flight Computer Testing section in README
    Removed redundant text about the schematic and adjusted image alignment.
2026-07-31 Update Firmware, hardware and notes
    [18mm Motor Retainer Simulations.SLDPRT, 18mm Motor Retainer.SLDPRT, 18mm Motor Retainer.STEP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]
2026-10-28 Add .gitignore; stop tracking KiCad local-history repos
2026-10-28 PCB: add rev 0.3 PDB and MCU boards (female BtB sockets on MCU, PWM1 on PB4)
2026-10-28 CAD: reorganise 60 mm airframe into Avionics Bay, Canards and Fin Can
2026-10-28 Firmware: update CubeMX config (single-PLL clocks, TIM3 canard PWM, NVIC, SPI3 12 MHz); code not yet regenerated
2026-10-28 Stop tracking KiCad backups and per-user project settings
2026-10-28 README: move images to Documentation/Images, update CAD and PDB renders, fix paths and repo tree
2026-10-28 Add avionics stack and board photos
2026-11-03 FC-V4: portable core, FDIR/phase scaffolding, USB flashing and flash log
    Restructure the F411 bench firmware into a HAL-free core (Core/hyades:
    gnc, mission, svc, math) and an F411 platform layer, per the software
    design guidelines and h743_flight_architecture.
    - app.c: boot sequence, 100 Hz rate-group task table with per-task WCET,
    checkpoint-gated IWDG, fault arbiter (READY gating, demotion, LOCKOUT/
    CATO_SAFE, control-mode ladder FULL -> RATE_DAMP -> OFF)
    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
2026-11-03 Tools: fc_console GUI (replaces Tera Term + fc_flash/fc_pull), fc_link, fc_sim, host tests
    - fc_link: USB link thread with auto-reconnect by VID:PID, stream demux for
    text lines / 0xAA55 STATE frames / LOGDATA capture, status/event parsers
    - fc_console: Tkinter console - persistent header (link, phase, ctrl mode,
    faults, data age, build), terminal with history/completion/find and pinned
    status line, dashboard, events table, USB flash (F5) and log pull+decode
    (F6) in worker threads, confirmed destructive actions locked out in flight,
    session log, field (light) / bench (dark) themes, text scaling
    - fc_sim: protocol-accurate simulated board (--sim) used by the tests
    - Tests/test_tools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
2026-11-03 GPS on port 2 (USART2/PA3) with line probe + baud hunt; faults clear; console v2
    Firmware
    - GPS: the module is on the board's USART2 header (PA3), as in the original
    V4 firmware; the 2 Nov refactor had moved the driver to USART1 (PA10), so it
    saw nothing. Both ports now receive into one ring. Boot probe classifies
    every UART line (floating / held high / held low), counts edges and infers
    the baud from the 4th-shortest pulse; a port receiving non-NMEA bytes steps
    through standard rates until sentences parse. Ring 512 -> 2048 B so the
    blocking boot calibration no longer overruns it. 'gps raw' / 'gps probe'.
    - 'faults clear' (pad only): served in task_fdir after the frame's monitors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
2026-11-03 IMU noise capture + Allan/GMWM tooling; GPS single port (USART2); build ID hash
    - GPS: fixed to USART2 (PA3) at 9600 now that the wiring is known; kept the
    boot line probe (rest levels, edges, bit time) for diagnosis; dropped the
    second port and the runtime baud hunt (-~70 lines of flight code).
    - 'imu capture': leaves the flight loop for good (fins centred, LEDs LOCKOUT,
    ends by reboot) and streams every ODR sample as raw counts with the sensor
    sample counter (MSG_IMU 0x02, 18 B). Config recorded in the IMUCAP line.
    - Tools/fc_imucap.py: overnight recorder (.imu + .json, incremental, gap
    accounting). Tools/fc_noise.py: overlapping ADEV, quantisation share
    (white, slope -1/2) and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
2026-11-03 IEKF noise from a 2.46 h static capture; fc_noise LPF-aware read-out
    - board.h: Q_ANGLE 1.49e-4 rad/s/rtHz (measured worst-axis ARW, 8.5
    mdps/rtHz incl. quantisation), Q_BIAS 1.29e-5 rad/s/rts (long-tau
    envelope, thermal drift included), R_ACCEL 1e-3 (sensor floor 4.3e-7 +
    0.03 g unmodelled pad acceleration). Derivation in the comment and
    Docs/noise/README.md.
    - fc_noise.py: white level read over tau 0.1-1 s and fit restricted to
    tau >= 0.1 s (below that the sensor LPF hump, not the noise model);
    Gauss-Markov time constant >= 1 s; rho from the total per-sample std;
    Q_BIAS from the long-tau envelope; unit fixes in the report.
    - Docs/noise: results, figures and metadata of captur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
2026-11-03 Update README with gyroscope testing results
    Added details about the ICM-42688-P gyroscopes being QMI8658A substitutes, including testing results and data analysis.
2026-11-03 Clarify gyroscope model and testing details in README
    Updated details about the gyroscope used, clarifying that the ICM-42688-P's are actually QMI8658A IMUs. Added information on the testing process and the model fitted to the data collected.
2026-11-07 NAV-01 vertical nav + flight-event detectors; HITL-01 PC-sim-in-the-loop
    Firmware (FC-V4):
    - gnc/nav: strapdown v/h in pad ENU from IEKF attitude, pad-measured gravity
    reference, q_hat = 1/2 rho_ISA(h) |v|^2, saturation flag, GPS altitude
    update after apogee with NIS gate and re-anchoring.
    - mission/detect: liftoff / burnout / apogee / landing persistence detectors
    with timer backups; run before the READY demotion, landing allowed with a
    HARD fault (DESCENT has no CATO edge).
    - hitl: CFG_HITL lockstep seam (0x10 SAMPLE, 0x11 REPLY, 0x12 NMEA), compiled
    out at 0; CFG_FLIGHT_BUILD guard; reboot accepted while HITL is live.
    - Text status gains h/vz/q; console Nav strip chart, body-rat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
2026-11-07 HITL worst-case campaign: q-scheduled roll law, nav bridging, liftoff gate
    - CTRL_ROLL_LAW 1: MATLAB Mode 1 law delta = -(c/qhat)p + bounded trim,
    40 kPa fallback when qhat invalid; replaces limit-cycling INDI roll gain
    - NAV bridges up to 8 dropped IMU frames in flight
    - Liftoff requires v_up > 8 m/s or 30-frame persistence (pad knock fix)
    - Plant: in-sensor vibration with pre-decimation clipping, dispersions,
    gusts, pad knocks, GPS faults; 29-case campaign runner and figures
    - HITL-02 results doc; ADR-003, HITL-01, NAV-01 updated
2026-11-08 ADR-004: 200 Hz synced loop, pre-trigger log, flight-core SITL, roll retune
    - 200 Hz frame, 448 Hz IMU, servo pulses started each frame (was 50 Hz
    async PWM); all persistence counts in ms (MS_TO_FRAMES)
    - flight.c: portable per-frame pipeline shared by app.c and the host SITL
    - Pre-trigger flight log: 2.56 s ring in the fw stage RAM, committed at
    liftoff, write-behind drain; log format v2 (h, v_up, q_hat, trim, AUX)
    - Roll law for the forward-body inertia (2.2e-4): c = 15, torque-space trim,
    band 0.3, q floor 1 kPa, large-error boost x4, 50 Hz dither
    - Landing by impact shock + stillness (no GPS needed); NAV clip budget;
    apogee timer 11.5 s; STM-01 state machine fixes F1-F3
    - Tools/s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
2026-11-08 Checkpoint decisions: full rate law for flight 1, tightened roll requirements, V6 IMU/high-g adopted
2026-11-08 Phase 2: flight loads (LD-01), recovery sub-sim (REC-01), SITL mass-property correction
    - SITL: dry CG 0.428->0.401 m, motor CG 0.835 m, dry It 0.053 (solved from the
    OpenRocket G79W export); cut-method station loads with closure check;
    deployment-state outputs; all MC-01 campaigns re-run (3 840 flights)
    - Tools/recovery: planar 4-body ejection/separation/cord/inflation Monte Carlo
    - Docs: LD-01, REC-01; MC-01/BP-01/ADR-004 updated
2026-11-08 REC-01: correct the motor-delay note (pressure/separation are speed-independent)
2026-11-08 STM-01 grid diagram, doc accuracy pass, PLAN-01 next steps
    - Phase machine redrawn on a left-to-right grid with T-numbered transitions
    (generated by stm01_phase_machine.py; replaces the Graphviz source)
    - STM-01: pad-knock path, terminal state and non-phase modes corrected
    - ADR-004/MC-01/BP-01/LD-01/REC-01: dates and post-CG-correction pass counts
    - PLAN-01: decisions, ground tests, development items, flight-1 gates
